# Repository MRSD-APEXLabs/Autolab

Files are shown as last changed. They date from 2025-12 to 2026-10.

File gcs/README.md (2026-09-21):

# GCS (Ground Control Station)

Operator-side stack: React UI, ROS2 GCS node bringup (rviz/rqt), MQTT bridges connecting the UI to ROS2, and an ELK monitoring stack.

## Layout

```
gcs/
├── docker/                          # docker-compose services for the GCS
│   ├── docker-compose.yaml          # gcs, gcs-real, ui, ui-dev, elasticsearch, kibana, filebeat
│   ├── gcs-base-docker-compose.yaml # shared ROS2 container definition (gcs-base)
│   ├── Dockerfile.gcs
│   └── monitoring/
│       ├── mosquitto/mosquitto.conf # MQTT broker config (ports 1883 + 9001 websocket)
│       └── filebeat/filebeat.yml
├── ui/                               # React web UI (Create React App)
└── ros_ws/src/
    ├── gcs_bringup/                  # top-level launch (rviz, rqt, domain_bridge, monitoring bridges, routine_executor)
    ├── gcs_monitoring/                # ROS2 <-> MQTT bridge nodes
    ├── routine_executor/              # runs operator-triggered routines (state machine)
    ├── rqt_gcs/                       # main rqt panel plugin (trajectory UI)
    └── rqt_autolab_control_panel/     # rqt operator control panel plugin
```

## UI

`gcs/ui` is a Create React App (React 19) that connects directly to the MQTT broker over WebSockets — it does not talk to ROS2 directly.

- Broker URL: `ws://<gcs-host>:9001` (`ui/src/App.js`), no ROS2 client involved.
- `mqtt` npm package used for pub/sub in the browser.

**Where it runs:**
- `ui` service (docker/docker-compose.yaml) — production build served by nginx on port `80` (override with `UI_PORT`). Built via `ui/Dockerfile.ui` (`prod` target: CRA build → nginx).
- `ui-dev` service — CRA dev server with hot reload on port `3000` (override with `UI_DEV_PORT`), profile `ui-dev`. Mounts `ui/src` and `ui/public` for live editing.
- Both build from `ui/Dockerfile.ui`; `dev` stage runs `npm start`, `prod` stage runs `npm run build` then serves via nginx.

Local (no Docker): `cd gcs/ui && npm install && npm start` (needs a broker reachable at `ws://localhost:9001`, e.g. from the `gcs` container's exposed `9001:9001` port).

Test/debug the UI's MQTT wiring without ROS2 using `ui/test_mqtt_status.py` (publishes/subscribes on `ros2/routine_executor/status` via the websocket port — see its docstring for usage).

## Bridges

MQTT is the transport between the browser UI and ROS2. Mosquitto runs inside the `gcs`/`gcs-real` container (`docker/monitoring/mosquitto/mosquitto.conf`): port `1883` for native MQTT, `9001` for MQTT-over-websockets (what the UI uses). Two ROS2 nodes in `gcs_monitoring` bridge the two worlds, both launched by `gcs_bringup/launch/gcs.launch.xml`:

- **`ros2_mqtt_bridge`** (`gcs_monitoring/ros2_mqtt_bridge.py`) — ROS2 → MQTT. Auto-discovers ROS2 topics every `ROS2MQTT_DISCOVERY_INTERVAL` seconds (default 10s), subscribes, and republishes each message as JSON to `ros2/<topic>` (e.g. `/odom` → `ros2/odom`). Skips `/tf`, `/tf_static`, `stereo` topics, and a hardcoded list of high-frequency/binary types (images, point clouds, IMU, joint states, TF, trajectories) to avoid flooding MQTT.
- **`mqtt_ros2_bridge`** (`gcs_monitoring/mqtt_ros2_bridge.py`) — MQTT → ROS2. Subscribes to a fixed set of UI command topics and republishes them as `std_msgs/String` on ROS2:
  - `cmd/routine_executor/start_routine_cmd` → `/routine_executor/start_routine_cmd`
  - `cmd/routine_executor/cancel` → `/routine_executor/cancel`

Both bridges connect to the broker at `MQTT_HOST`:`MQTT_PORT` (default `localhost:1883`, i.e. native MQTT — not the websocket port used by the browser), retrying until Mosquitto is up.

There's also a **`domain_bridge`** node (not MQTT — a ROS2 `domain_bridge` instance) configured by `gcs_bringup/config/domain_bridge.yaml`, which relays specific topics between ROS domain 0 (robot) and domain 1 (GCS) — behavior tree commands, joint states, fixed-trajectory commands, and bag-recording status/control.

## GCS ROS2 bringup

`ros2 launch gcs_bringup gcs.launch.xml` starts, in one process group:

1. `rviz2` with `rviz/gcs.rviz`
2. `rqt_gui` with the `config/gcs.perspective` layout (hosts the `rqt_gcs` and `rqt_autolab_control_panel` plugins)
3. `domain_bridge` (domain 0 ↔ 1 relay, see above)
4. `ros2_mqtt_bridge` and `mqtt_ros2_bridge` (monitoring bridges, see above)
5. `routine_executor_node` (executes operator-triggered routines; commanded via the MQTT bridges above)

All nodes `respawn` on crash. This launch runs automatically inside the `gcs`/`gcs-real` container when `AUTOLAUNCH=true` (see root `.env`), or manually via `autolab connect gcs` then `bws && sws && ros2 launch gcs_bringup gcs.launch.xml`.

## Monitoring stack (ELK)

`elasticsearch`, `kibana`, and `filebeat` services (docker/docker-compose.yaml) ship container logs for the `sitl`/default/`simple` profiles only — `gcs-real` uses `network_mode: host` and isn't covered by this stack. Kibana UI on `5601`, Elasticsearch API on `9200`. Config: `docker/monitoring/filebeat/filebeat.yml`.

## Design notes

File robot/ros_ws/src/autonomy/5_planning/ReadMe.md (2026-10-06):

# Planning: how to run it

The arm moves from step 4. Keep the E-stop in reach and the workspace clear. Nothing else may command the arm (no
joystick script, no UFactory Studio).

The point cloud, AprilTags and well plate detections come from the perception stack (`3_perception`). The planner
reads the topics it publishes: `/zed_pointcloud`, `/inspect/apriltags` and `/inspect/wellplates`.

## 1. Network (Thor)

```bash
ip -4 -br addr | grep enP2p1s0            # must be UP, 192.168.1.100
ping -c1 192.168.1.236 && echo ARM OK
ping -c1 192.168.1.101 && echo XAVIER OK
```

## 2. Camera hub (Xavier)

The hub runs at boot (`camera-hub.service`). Check that it answers:

```bash
curl -s http://192.168.1.101:8090/status   # "server": "camera_hub", "state": "streaming"
```

If it doesn't answer, restart it on the Xavier:

```bash
ssh autolab@192.168.1.101 'sudo systemctl restart camera-hub.service'
```

## 3. Perception (Thor host, not the container)

Use a new terminal. `~/.bashrc` already sets up ROS Jazzy, `ROS_DOMAIN_ID=1` and the loopback FastDDS profile.
The packages are built in `~/ros2_ws` from `~/apple_server_manip/2_manipulation`.

```bash
source ~/ros2_ws/install/setup.bash
source /home/labx/apple_server_manip/.venv/bin/activate        # torch for the depth nodes
ros2 launch camera_perception perception.launch.xml with_cameras:=true \
  depth_models_dir:=/home/labx/apple_server_manip/data/models
```

The hub streams one camera at a time, and the point cloud only comes from the ZED X. Select it (takes ~6 s):

```bash
ros2 service call /camera_hub/select_zedx std_srvs/srv/Trigger
```

Check:

```bash
ros2 topic hz /zed_pointcloud                  # up to 5 Hz
ros2 topic echo --once /inspect/wellplates     # a "wellplates" marker when a plate is in view
```

## 4. Planning stack (Thor → container): the arm enables here

After a `git pull`, rebuild in the container first: `autolab connect robot`, then `bws`.

```bash
xhost +local:
docker start autolab-robot-l4t-1                                          # skip if already running
docker exec autolab-robot-l4t-1 tmux kill-session -t robot_bringup        # stop the auto full-stack launch ("no server running" is fine)
docker exec -it autolab-robot-l4t-1 bash -lc 'export DISPLAY=:1 ROS_LOCALHOST_ONLY=1 FASTRTPS_DEFAULT_PROFILES_FILE=/home/robot/AutoLab/common/ros_packages/fastdds_loopback.xml; ros2 launch planning_bringup planning.launch.xml robot_ip:=192.168.1.236 show_rviz:=true'
# ready when "Received command: idle" repeats (~30 s); RViz opens with the planner path display
```

Always use `bash -lc`. Without it, the stack comes up on the wrong ROS domain and ignores every command.

## 5. Plan (Thor)

```bash
# terminal A
ros2 topic echo /planning_state
```

```bash
# terminal B: one at a time, wait for PLANNING → EXECUTING → SUCCESS
ros2 topic pub --once /planning_command std_msgs/String "{data: 'plan_home_offset'}"   # fixed safe pose, no camera needed. Do this first
ros2 topic pub --once /planning_command std_msgs/String "{data: 'plan_home'}"          # home point (via top_camera TF)
ros2 topic pub --once /planning_command std_msgs/String "{data: 'plan_april_1'}"       # 25 cm above AprilTag 1 (OT-2)
ros2 topic pub --once /planning_command std_msgs/String "{data: 'plan_april_2'}"       # 25 cm above AprilTag 2 (shaker)
ros2 topic pub --once /planning_command std_msgs/String "{data: 'plan_wellplate'}"     # 25 cm above the detected well plate
ros2 topic pub --once /planning_command std_msgs/String "{data: 'idle'}"
```

- **The obstacle cloud is frozen at the first `plan_*` command.** The planner forwards the latest `/zed_pointcloud`
  once to `/zed_pointcloud_frozen`, which is the only cloud MoveIt reads. Every later plan uses that cloud. To take a
  new one, restart the planning launch (step 4).
- `plan_april_<id>` and `plan_wellplate` wait up to 10 s for a detection less than 1 s old, or end in `ERROR`.
- The wrist must be within ~11° of straight down before the first plan, or you get
  `Waypoint 0 FAILED ee_down constraint`.
- RViz shows two lines per plan: orange is the raw planner path, cyan is the path after shortcutting.
- The planner is chosen by `PLANNER` in `global_planner/src/move_to_pose_node.cpp` (`RRT_CONNECT` |
  `INFORMED_RRTSTAR` | `PRM`). After changing it, rebuild and relaunch step 4:

```bash
docker exec autolab-robot-l4t-1 bash -lc 'cd ~/AutoLab/robot/ros_ws && colcon build --symlink-install --packages-select global_planner'
```

## 6. Stop

Ctrl-C the planning launch (step 4), then Ctrl-C the perception launch (step 3).

## Code

The main logic is in `global_planner/src/move_to_pose_node.cpp`. The commands on `/planning_command`
(`std_msgs/String`) are `plan_april_<id>`, `plan_wellplate`, `plan_home`, `plan_home_offset` and `idle`.

Future improvements:
- [Design] Put all config params in one file.
- [Design] `move_to_pose_node.cpp` is ~1000 lines; split it into smaller pieces.

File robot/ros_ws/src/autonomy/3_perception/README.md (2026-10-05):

# 3_perception: ZED X / ZED X Nano cameras, stereo depth, camera UI, perception and live ACT inference

This folder is self-contained. It holds the camera stack and the inference half of the teleop/ACT pipeline, ready
to move into a larger codebase:

| folder | what | depends on |
|---|---|---|
| `zedx_nano_camera/` | ROS 2 package (ament_python). Publishes a camera feed from the Xavier: JPEG, raw BGR and `CameraInfo` for each eye. Serves either camera of the camera hub (`camera` parameter). Also holds `camera_hub_node`, the ROS bridge to the hub (status topic, select services) | `rclpy`, `sensor_msgs`, `std_srvs`, `cv_bridge`, numpy, OpenCV. No ZED SDK |
| `zedx_nano_depth/` | ROS 2 package. Subscribes to the stereo pair, rectifies it, computes depth with RAFT-Stereo (GPU) or SGBM (CPU) and publishes depth plus the rectified left image | `zedx_nano_camera`; torch for the neural backend |
| `camera_ui/` | ROS 2 package. Web page on port 8001 that switches the hub between the two cameras and shows the active camera's RGB and depth. Its launch file starts the whole camera stack | `zedx_nano_camera`, `sensor_msgs`, `std_srvs`, `cv_bridge`, numpy, OpenCV |
| `camera_perception/` | ROS 2 package. AprilTags, YOLO detections and (ZED X only) a point cloud from the depth node's outputs, published under the topic names of the old Autolab `pc3.py` bridge (`/inspect/*`, `/servo/*`, `/zed_pointcloud`) | `zedx_nano_depth`, `camera_ui` (launch only), `cv_bridge`; pip: `pupil-apriltags`, `ultralytics` (torch) |
| `xavier_camera_hub/` | Not a ROS package (`COLCON_IGNORE`). HTTP server that runs **on the Xavier** (`/home/autolab/camera_hub/`) and streams one camera at a time. See [its README](xavier_camera_hub/README.md) | Python 3.8, numpy, OpenCV, pyzed (ZED X), `v4l2-ctl` (Nano) |
| `act_inference/` | Plain Python, not a ROS package (`COLCON_IGNORE`). Live ACT rollout on the xArm6. Contains a trimmed copy of the ACT/DETR model code | the ROS packages above as libraries; torch, xArm SDK |

The package names still say "nano", but `zedx_nano_camera` and `zedx_nano_depth` serve both cameras.

Relationship:

```
Xavier: xavier_camera_hub (port 8090), streams ONE camera at a time
   │  ZED X (SN 42757821, base) via pyzed   or   ZED X Nano (SN 99292912, wrist) via raw V4L2
   │  /select, /status, /cameras/<cam>/{video_feed/stereo,calibration.conf,info}, /time
   │
   ├──► camera_hub_node ──► /camera_hub/status, /camera_hub/select_{zedx,zedx_nano}, /camera_hub/release
   ├──► zedx_nano_camera (camera:=zedx)      ──► /zedx/{left,right}/…      ──► zedx_nano_depth ──► /zedx/depth/…
   ├──► zedx_nano_camera (camera:=zedx_nano) ──► /zedx_nano/{left,right}/… ──► zedx_nano_depth ──► /zedx_nano/depth/…
   │                                                                             │
   │                               camera_ui (http://<thor>:8001/) ◄─────────────┤ both namespaces + /camera_hub
   │                               camera_perception ◄───────────────────────────┤ /inspect/*, /zed_pointcloud, /servo/*
   │                               act_inference --camera-source ros ◄───────────┘
   └──► legacy root routes (Nano only): act_inference --camera-source nano-stream, teleop/nano_stream.py
```

The nodes of the camera that is not selected stay connected to the hub and wait; they start publishing within
about a second of a switch. Both camera sources of `act_inference` feed the policy identical frames. The
rectification maps, depth pipeline and ACT preprocessing are copies of `teleop/` and `act/` (see
[Verification](#verification)). The old Nano-only server (`scripts/zedx_nano_v4l2_stream.py`,
`zedx-nano-stream.service`) stays in the repo root; the hub replaces it on port 8090 and keeps its routes.

## Camera UI (ZED X and ZED X Nano)

Build the packages (see [Build](#build)), then on the Thor:

```bash
source /opt/ros/humble/setup.bash && source ~/ros2_ws/install/setup.bash
source /home/labx/apple_server_manip/.venv/bin/activate          # torch for the RAFT depth nodes
ros2 launch camera_ui camera_ui.launch.xml models_dir:=/home/labx/apple_server_manip/data/models
```

Open `http://<thor>:8001/`. The two buttons at the top right select the ZED X (base) or the ZED X Nano (wrist);
**Release** stops both. The left panel shows the rectified left image and the right panel shows depth (TURBO:
red near, blue far, black invalid) with its colorbar, auto range or a fixed near/far range in mm. Hovering over
either image shows the depth and the optical-frame XYZ at that pixel. **PNG** saves the RGB image, **PNG 16-bit**
saves the depth in mm. The rates, frame age, valid-pixel ratio and median depth appear under each panel.

A switch takes about 6 s to the ZED X (the ZED SDK opens the camera) and about 2 s to the Nano. The same switch
from a terminal or another node:

```bash
ros2 service call /camera_hub/select_zedx std_srvs/srv/Trigger
ros2 service call /camera_hub/select_zedx_nano std_srvs/srv/Trigger
ros2 service call /camera_hub/release std_srvs/srv/Trigger
ros2 topic echo --once /camera_hub/status                        # JSON: active camera, state, rates
curl -X POST -H 'Content-Type: application/json' -d '{"camera": "zedx"}' http://<thor>:8001/api/select
```

`/api/select` accepts only `Content-Type: application/json` and refuses cross-origin requests, so another web
page cannot switch the camera. The hub's own page, `http://192.168.1.101:8090/`, also switches cameras and shows
the raw left/right preview.

`camera_ui.launch.xml` arguments:
- `with_cameras` (true): also start `cameras.launch.xml`, i.e. the hub bridge plus a camera node and a depth node
  per camera. Use `with_cameras:=false` when the camera stack already runs.
- `ui_host` (0.0.0.0) and `ui_port` (8001): where the page is served. The page can switch cameras, so use
  `ui_host:=127.0.0.1` to keep it off the network.
- `host` and `port`: the Xavier hub (192.168.1.101, 8090).
- `backend`, `models_dir` and `repo`: passed to both depth nodes.
- `zedx_depth_model` (fast-foundation) and `zedx_nano_depth_model` (`model`, i.e. raft-realtime): the depth
  model per camera. The base camera takes accuracy over rate, the wrist camera the rate
  (see [Depth models](#depth-models)). `model` sets the default for any camera without its own argument.
- `zedx_temporal_frames` (5) and `zedx_nano_temporal_frames` (1): the temporal median per camera.
- `ui_params_file`: the UI parameters, `config/camera_ui.yaml` by default.

`ros2 launch camera_ui cameras.launch.xml` starts the camera stack without the page.

UI HTTP API, for scripts:

| request | answer |
|---|---|
| `GET /api/status` | hub status, per-camera stream rates, depth statistics, intrinsics |
| `POST /api/select` `{"camera": "zedx" \| "zedx_nano" \| null}` | switch (null releases); waits up to 45 s for the first frame |
| `GET /api/depth_at?camera=&u=&v=` | depth (mm) and optical-frame XYZ (mm) at normalized image coordinates |
| `GET /stream/<cam>/rgb.mjpg` | rectified left image; the raw JPEG while no depth node runs |
| `GET /stream/<cam>/depth.mjpg?near=&far=&auto=1` | colorized depth |
| `GET /snapshot/<cam>/rgb.png`, `/snapshot/<cam>/depth.png` | the latest frame; depth as 16-bit PNG in mm |

## Perception: AprilTags, YOLO and the ZED X point cloud

`camera_perception` replaces the Xavier's Autolab-Camera-Edge "inspect" (ZED X) and "servo" (Nano) workers and the
`~/coding/Autolab/pc3.py` bridge that republished them. It runs on the Thor, on the rectified image and depth of the
camera stack above, and publishes under the topic names `pc3.py` used, so the planner (`move_to_pose_node`) and
MoveIt read it unchanged. There is one node per camera: `/zedx/zedx_perception` and `/zedx_nano/zedx_nano_perception`.
Like the depth nodes, the node of the camera the hub is not streaming logs once that it is idle and waits.

One-time setup, in the venv that runs the nodes (it must see the system site packages). `--no-deps` keeps pip from
installing `opencv-python`, which would shadow the system cv2 that `cv_bridge` uses:

```bash
source /home/labx/apple_server_manip/.venv/bin/activate
pip install pupil-apriltags
pip install --no-deps ultralytics 'filelock>=3.16.1' cloudpickle ultralytics-thop nvidia-ml-py
```

The YOLO weights are in `data/models/yolo/`:
- `best_wrist.pt`: oriented boxes, class `wellplate`, from Camera-Edge servo. The default for both cameras.
- `best_top.pt`: the same kind of model, from Camera-Edge inspect. It did not find the clear plate on the ZED X
  deck (below).
- `best_seg.pt`: segmentation, from `~/coding/Autolab`.

Run it next to the camera stack (the camera UI launch), or start the stack with it:

```bash
source /opt/ros/humble/setup.bash && source ~/ros2_ws/install/setup.bash
source /home/labx/apple_server_manip/.venv/bin/activate
ros2 launch camera_perception perception.launch.xml                          # camera stack already running
ros2 launch camera_perception perception.launch.xml with_cameras:=true \
  depth_models_dir:=/home/labx/apple_server_manip/data/models                  # also start hub bridge, camera, depth
ros2 launch camera_perception perception.launch.xml zedx_nano:=false cloud_mode:=snapshot fresh:=true
```

Use the same `ROS_DOMAIN_ID` as the camera stack and the planner.

### Topics

| `pc3.py` | camera_perception | type | contents |
|---|---|---|---|
| `/inspect/apriltags` | same | `MarkerArray` | `DELETEALL`, then one red 2 cm `SPHERE` per tag with a pose: `id` = tag id, ns `apriltags`, orientation = tag frame. Nothing else, because the planner stores every ADD marker's position under its id |
| `/inspect/wellplates` | same | `MarkerArray` | `DELETEALL`, then per detection with a pose a green `CUBE` (ns `wellplates`, id i, metric size) and a label (ns `wellplates_text`, id 1000+i). Detections are sorted by ascending confidence, so the most confident one is the last `wellplates` marker, the one the planner takes |
| `/zed_pointcloud` | same | `PointCloud2` | x, y, z float32 (+ packed `rgb`), frame `top_camera`, for MoveIt's octomap |
| `/inspect/image`, `/inspect/annotated_image` | same | `Image` bgr8 | the input image, and the image with tags, boxes and axes drawn. Published only while subscribed |
| – | `/inspect/json` | `String` | the frame's tags and detections: pixel geometry, poses, pose source, tag size measured by depth, reprojection error |
| – | `/inspect/capture_snapshot` | `std_srvs/Trigger` | snapshot mode: capture a new cloud |
| `/servo/image`, `/servo/annotated_image`, `/servo/detections` | same | as above | Nano. Detections: the best one only, ns `servo_detections` |
| – | `/servo/apriltags`, `/servo/json` | as above | Nano tags and JSON |
| `/servo/target` | **not published** | | it needs a Nano hand-eye calibration, which doesn't exist yet |

All outputs carry the image stamp. The ZED X outputs are labelled `top_camera`, the frame that the robot's TF tree
(`Chassis_1 → top_camera`) and the planner use for this camera. The launch file also publishes an identity
`top_camera → zedx_left_camera_optical_frame` (`top_camera_tf:=false` turns it off), so the `/zedx` camera
topics fit into that tree too. The Nano outputs keep `zedx_nano_left_camera_optical_frame`.

### What is computed

- **AprilTags:** `pupil_apriltags`, tag36h11, ids 0, 1, 2, 21 and 22, 62.5 mm, at full resolution.
  - Pose from `solvePnPGeneric` (IPPE_SQUARE) on the corners and the tag size. The depth inside the tag gives a
    plane that picks between the two mirror-image PnP solutions and measures the tag's actual size. The node warns
    when that size is more than 15 % off; set `apriltags.sizes` (`'21=0.075'`) for tags printed at another size.
  - `apriltags.position: depth` takes the position from the depth plane instead of the size.
  - The orientation is the AprilTag library's tag frame (x right, y down, z into the tag, in the tag's own
    orientation). The Camera-Edge code built it from image-sorted corners, so its orientation differed.
    `calibrate_top_camera.py` fits position only by default.
  - A small tag seen face-on (~40 px) has a few degrees of tilt uncertainty. Its position and in-plane angle stay
    sharp.
- **YOLO:** ultralytics, on the GPU (falls back to CPU). Oriented-box, box and segmentation models are handled.
  The ZED X keeps only the class `wellplate` (`yolo.classes`), since the planner takes the last marker on
  `/inspect/wellplates` whatever its class.
  - On the ZED X the model input gets CLAHE first (`yolo.clahe_clip` 3, `yolo.clahe_tiles` 4; contrast
    equalization of the lightness in 4×4 tiles). The deck is dim, and a clear plate on it is invisible to the
    models without it. Outputs and the annotated image use the original image.
  - Each detection is placed with a RANSAC plane fit on the depth inside its box or mask. Position: the centre ray
    meets the plane. z: the plane normal toward the camera. x: along the box's width, which is the long side for
    oriented boxes. Size: in metres.
  - Detections without valid depth appear in the JSON and the annotated image but get no marker. `pc3.py` gave
    those a pixel-scaled placeholder.
  - If the model fails to load or run, the node logs the error and continues with tags and the cloud.
- **Point cloud (ZED X only):**
  - Every 4th pixel of the depth, cropped to x, y ∈ ±0.6 m and z ∈ 0.2–1.7 m (camera frame). Points on depth
    edges (a jump over 2 % of the depth per pixel) are dropped, then one point is kept per 1 cm voxel: about
    10k points per cloud.
  - `cloud_mode:=live` (default): a new cloud up to 5 times a second, so the octomap follows the scene.
  - `cloud_mode:=snapshot`: `pc3.py`'s behaviour. 10 frames are stacked once, saved to
    `~/.ros/camera_perception/zedx_snapshot.npy` and republished at 5 Hz stamped with the current time. A cached
    cloud is loaded at start-up, even without a camera. `pc3.py`'s N×3 `.npy` files load as well.
    `/inspect/capture_snapshot` or `fresh:=true` captures a new one.
  - With `fresh:=true` or after `capture_snapshot`, the old cloud stays published until the new one is complete.
    Then the node calls `/clear_octomap` and publishes the new cloud. So MoveIt is never left without obstacles,
    even if the hub is streaming the Nano. If move_group doesn't answer within 40 timer ticks (8 s at 5 Hz), the
    node publishes anyway. Live mode with `fresh:=true` clears the same way, before its first cloud.
    A failed cache write is logged, and the cloud is still published.

The ZED X node processes at most 10 frames/s (`max_rate`). At every frame (~16/s) it would take about 1.3 CPU
cores, mostly for the full-resolution tag detection. The Nano node processes every frame.

`perception.launch.xml` arguments:
- `zedx`, `zedx_nano` (true): which cameras get a node.
- `yolo_models_dir` (`data/models/yolo`), `zedx_model` (best_wrist.pt), `zedx_nano_model` (best_wrist.pt),
  `device` (cuda:0).
- `cloud_mode` (live | snapshot) and `fresh` (false).
- `top_camera_tf` (true).
- `zedx_params_file`, `zedx_nano_params_file`: `config/zedx.yaml` and `config/zedx_nano.yaml` hold every other
  parameter, with comments.
- `with_cameras` (false), `host`, `port`, `depth_backend`, `depth_models_dir`, `depth_repo`: for starting the
  camera stack too. The per-camera depth models are the camera stack's defaults; override them there.
  `perception_bringup` passes the same arguments through.

`camera_perception`, `camera_ui`, `zedx_nano_camera` and `zedx_nano_depth` are shared with
`apple_server_manip/2_manipulation`, where they are developed on Jazzy. The two copies are kept identical
except that this one ships the YOLO weights inside `camera_perception` (`models/yolo`, installed by
`setup.py`) and defaults `yolo_models_dir` to the package share. Port changes both ways.

## Live ACT inference

Prediction-only by default: robot state is read, the policy runs, the limited targets are
printed, and the arm is not enabled or commanded. Keep `policy_best.ckpt`, `config.pkl` and
`dataset_stats.pkl` together in the checkpoint folder. RGB versus RGB-D is detected from the checkpoint.

From the repo root, with the project venv:

```bash
OMP_NUM_THREADS=2 .venv/bin/python 2_manipulation/act_inference/run_act_inference.py \
  --ckpt-dir data/act_ckpts/xarm6_rgbd --duration-sec 30 --preview \
  --depth-models-dir data/models
```

`--depth-models-dir data/models` reuses the RAFT weights already in the repo. Without it the
weights go to `$ZEDX_NANO_DEPTH_MODELS` or `~/.cache/zedx_nano_depth` and are downloaded
(40 MB) on the first run.

For an operator-attended run, place the arm at the demonstrated start pose, stop any other
controller (teleop, AutoLab planning) and add `--execute`:

```bash
OMP_NUM_THREADS=2 .venv/bin/python 2_manipulation/act_inference/run_act_inference.py \
  --ckpt-dir data/act_ckpts/xarm6_rgbd --duration-sec 5 --translation-speed 0.01 \
  --depth-models-dir data/models --execute --preview
```

Ctrl-C, Enter, or `q`/Esc in the preview stops the run. Every target is speed-limited
(`--translation-speed` 0.025 m/s, `--rotation-speed` 0.1 rad/s) and must stay inside
`--workspace-radius` (0.1 m) of the start pose. The run stops if a prediction is older than
`--prediction-timeout` (0.75 s) or the camera frame is stale (`--max-frame-age` 0.25 s plus
two depth periods). Orientation is held unless `--enable-rotation` is given. There is no gripper output.

### Camera sources

- `--camera-source nano-stream` (default) reads stereo pairs from the Xavier (`--camera-host`
  192.168.1.101, `--camera-port` 8090) and computes depth in this process (`--depth-backend
  neural|sgbm`, `--depth-model`, `--depth-width`). It needs no ROS.
- `--camera-source ros --ros-namespace /zedx_nano` reads `left/image_rect_color`,
  `depth/image_rect` and `depth/camera_info` from a running `zedx_nano_depth` node, so one
  depth network serves both the robot stack and the policy. Source ROS first
  (`source /opt/ros/humble/setup.bash`) and use the same `ROS_DOMAIN_ID` as the nodes. The
  `--depth-*` options don't apply here; the depth node's parameters do. It runs a private
  rclpy context, so it can be embedded in a process that already uses rclpy.

`run_act_inference.py --help` lists all options. `act_inference/requirements.txt` lists the Python dependencies.

### Using it as a library

`act_inference/act_inference/__init__.py` adds `zedx_nano_camera/` and `zedx_nano_depth/` to
`sys.path` when they sit next to it. So once `2_manipulation/act_inference` is on the path, no
build step is needed:

```python
import sys; sys.path.insert(0, '2_manipulation/act_inference')
from pathlib import Path
from act_inference.config import InferenceConfig, RolloutConfig
from act_inference.rollout import run_act_rollout

run_act_rollout(InferenceConfig(camera_source='ros', ros_namespace='/zedx_nano'),
                RolloutConfig(ckpt_dir=Path('data/act_ckpts/xarm6_rgbd'), duration_sec=30))
```

Lower-level pieces:
- `rollout.load_policy` and `rollout.predict_chunk` for the model.
- `cameras.make_camera` for a `CameraFrame` source.
- `robot.XArm6Robot(read_only=True)` for the arm.

## ROS 2 packages

### Build

The packages were originally built and tested against ROS 2 Jazzy (Python 3.12); this repo runs Humble
(Python 3.10). Audited 2026-09-22: no Jazzy-only rclpy/launch API or Python 3.11+/3.12-only syntax found in
`zedx_nano_camera`, `zedx_nano_depth`, `camera_ui` or `camera_perception` — none was ever run on Humble though,
so treat a first build as unverified. Link or copy them into a workspace:

```bash
mkdir -p ~/ros2_ws/src && ln -s /home/labx/apple_server_manip/2_manipulation ~/ros2_ws/src/2_manipulation
cd ~/ros2_ws && source /opt/ros/humble/setup.bash
colcon build --packages-select zedx_nano_camera zedx_nano_depth camera_ui camera_perception
source install/setup.bash
```

colcon skips `act_inference` and `xavier_camera_hub` because of their `COLCON_IGNORE`. Build **without**
`--symlink-install`. The node scripts then use `#!/usr/bin/env python3`, so they run in whichever Python is first
on `PATH`. With `--symlink-install`, colcon writes `#!/usr/bin/python3` into them instead, and the depth nodes
fail because the system Python has no CUDA torch. The neural depth
backend needs torch, so activate a venv that has torch and the system site packages before
`ros2 launch`, e.g. `source /home/labx/apple_server_manip/.venv/bin/activate`. The camera node
and the `sgbm` backend need only the system Python. torch isn't a rosdep key, so `package.xml` doesn't declare it.

### Launch

The camera UI's launch file starts the full two-camera stack (see [Camera UI](#camera-ui-zed-x-and-zed-x-nano)):

```bash
ros2 launch camera_ui camera_ui.launch.xml models_dir:=/home/labx/apple_server_manip/data/models   # stack + page
ros2 launch camera_ui cameras.launch.xml models_dir:=/home/labx/apple_server_manip/data/models      # stack only
ros2 launch zedx_nano_camera camera_hub.launch.xml                                                 # hub bridge only
```

Single cameras:

```bash
# ZED X depth (also starts its camera node) in /zedx
ros2 launch zedx_nano_depth zedx_nano_depth.launch.xml camera:=zedx namespace:=zedx \
  models_dir:=/home/labx/apple_server_manip/data/models

# Nano camera only
ros2 launch zedx_nano_camera zedx_nano_camera.launch.xml host:=192.168.1.101

# depth, also starts the camera (with_camera:=true is the default)
ros2 launch zedx_nano_depth zedx_nano_depth.launch.xml models_dir:=/home/labx/apple_server_manip/data/models

# depth only, camera already running in the same namespace
ros2 launch zedx_nano_depth zedx_nano_depth.launch.xml with_camera:=false

# CPU depth, no torch needed
ros2 launch zedx_nano_depth zedx_nano_depth.launch.xml backend:=sgbm
```

Launch arguments:
- Camera: `namespace` (zedx_nano), `camera`, `name` (node name), `host`, `port`, `sensor`, `params_file`.
- Depth: `namespace`, `with_camera`, `camera`, `host`, `port`, `backend`, `model`, `models_dir`, `params_file`.
- Hub bridge: `host`, `port`, `params_file`.

`camera` selects a hub camera: `zedx` or `zedx_nano`. It also names the frames. Use a matching `namespace`.
The default, `''`, reads the hub's legacy root routes, which serve the Nano, and the old Nano-only server.
A single-camera launch does not switch the hub; select its camera in the UI or with the
`/camera_hub/select_*` services (with the hub bridge running) or `POST /select` on the Xavier.

The remaining parameters are read from `config/*.yaml`. Each file's header says which values the launch file overrides.

### Topics (namespaces `/zedx` and `/zedx_nano`)

Each camera has its own namespace with the same topics. The camera UI launch uses `/zedx` for the ZED X and
`/zedx_nano` for the Nano.

| topic | type | from | notes |
|---|---|---|---|
| `{left,right}/image_raw/compressed` | `CompressedImage` | camera | the Xavier's JPEG, forwarded without re-encoding |
| `{left,right}/image_raw` | `Image` bgr8 | camera | unrectified; decoded only while something subscribes |
| `{left,right}/camera_info` | `CameraInfo` | camera | factory K, D and stereo rectification R, P. Right `P[0,3] = -fx·B` in meters |
| `depth/image_rect` | `Image` 16UC1 | depth | depth in mm, 0 = invalid, aligned to `left/image_rect_color` |
| `depth/camera_info` | `CameraInfo` | depth | rectified pinhole model (D = 0) for `depth/image_rect` and `left/image_rect_color` |
| `left/image_rect_color` | `Image` bgr8 | depth | the rectified left image that the depth belongs to |
| `depth/colorized` | `Image` bgr8 | depth | preview: red near, blue far, black invalid. Computed only while subscribed |

With `sensor:=left` or `right`, the camera publishes only that eye; the depth node needs `stereo`.

The hub bridge, `camera_hub_node`, is not namespaced:

| name | type | notes |
|---|---|---|
| `/camera_hub/status` | `std_msgs/String` (JSON), transient local | the hub's `/status` (`active`, `state`, `error`, per-camera `fps`) plus `reachable`, `poll_error`, `hub_url`; published after every poll |
| `/camera_hub/select_zedx`, `/camera_hub/select_zedx_nano` | `std_srvs/Trigger` | switch the hub; returns when the camera streams (`success`, `message` e.g. `zedx streaming`) or fails |
| `/camera_hub/release` | `std_srvs/Trigger` | stop both cameras |

### Parameters

| node | parameter | default | |
|---|---|---|---|
| camera | `host`, `port` | 192.168.1.101, 8090 | Xavier camera hub |
| camera | `camera` | '' | zedx or zedx_nano; '' = the hub's legacy root routes (the Nano) |
| camera | `sensor` | stereo | stereo, left or right |
| camera | `timeout` | 3.0 s | HTTP timeout; longest stall before reconnecting |
| camera | `left_frame_id`, `right_frame_id` | '' | '' = `<camera>_{left,right}_camera_optical_frame` (`zedx_nano_…` for camera '') |
| camera | `clock_sync_period` | 10 s | Xavier clock re-synchronization |
| camera | `max_sync_uncertainty` | 0.05 s | reject a clock sync that is less precise than this |
| camera | `reconnect_delay` | 1.0 s | |
| camera | `inactive_poll_period` | 1.0 s | how often to retry while the hub streams the other camera |
| depth | `backend` | neural | neural (RAFT-Stereo, GPU) or sgbm (OpenCV, CPU) |
| depth | `model` | raft-realtime | raft-realtime, raft-middlebury, fast-foundation or a `.pth` path |
| depth | `models_dir` | '' | '' = `$ZEDX_NANO_DEPTH_MODELS` or `~/.cache/zedx_nano_depth`. Missing RAFT weights are downloaded |
| depth | `repo` | '' | fast-foundation only: checkout path ('' = `<models_dir>/Fast-FoundationStereo`). The repo's copy is `third_party/Fast-FoundationStereo` |
| depth | `match_width` | 640 | px; the width at which disparity is computed |
| depth | `temporal_frames` | 1 | >1 publishes the per-pixel median of that many frames (the camera stack gives the ZED X 5). For a camera that does not move; the window is dropped after a 1 s gap or a new calibration |
| depth | `max_depth_mm` | 4000 | farther depth is published as 0 |
| depth | `input_transport` | compressed | compressed (JPEG) or raw (`image_raw`) |
| depth | `colorize_near_mm`, `colorize_far_mm` | 100, 1000 | `depth/colorized` range |
| camera_hub | `host`, `port` | 192.168.1.101, 8090 | Xavier camera hub |
| camera_hub | `cameras` | [zedx, zedx_nano] | one `select_<camera>` service each |
| camera_hub | `poll_period`, `timeout` | 1.0 s, 3.0 s | `/status` polling |
| camera_hub | `select_timeout` | 30 s | how long a select waits for the camera's first frame |
| camera_ui | `host`, `port` | 0.0.0.0, 8001 | where the page is served (launch: `ui_host`, `ui_port`) |
| camera_ui | `cameras`, `labels` | [zedx, zedx_nano], [ZED X (base), ZED X Nano (wrist)] | topics are read from `/<camera>/…` |
| camera_ui | `max_fps`, `jpeg_quality` | 15, 80 | per browser stream |
| camera_ui | `stale_after` | 1.0 s | older frames are marked stale on the page |
| camera_ui | `hub_node` | /camera_hub | the hub bridge's status topic and services |

### Depth models

Measured on the Jazzy machine (Thor, CUDA) against the ZED X: 10 stereo pairs of the room and floor at 1.2-3.7 m,
and 10 of the Opentrons deck at 0.86 m. *Flicker* is the median standard deviation of one pixel's depth over the
pairs of a still scene; *plane residual* is what a plane fitted in 15x15 windows leaves, i.e. how rough a locally
flat surface looks.

| ZED X, `match_width` 640 | flicker (room) | flicker (deck) | plane residual | per pair |
|---|---|---|---|---|
| sgbm | 33.7 mm | | 31.9 mm | 29 ms |
| raft-realtime | 34.7 mm | 35.7 mm | 2.1 mm | 51 ms |
| raft-realtime + median of 5 | | 10.5 mm | 2.6 mm | 51 ms |
| raft-middlebury | 17.6 mm | | 8.9 mm | 481 ms |
| fast-foundation | 6.1 mm | 11.4 mm | 1.1 mm | 171 ms |
| **fast-foundation + median of 5** | | **3.2 mm** | 1.1 mm | 171 ms |

So the camera stack runs the ZED X on fast-foundation with `temporal_frames: 5` (~6-9 fps, which the base camera
can afford: perception caps at 10 Hz and the point cloud at 5 Hz) and leaves the Nano on raft-realtime with no
median, because the visual servo needs the rate and the low lag, not the millimetres. The median is per pixel over
the last N frames (`np.partition`, 9 ms); its window is dropped when the input stops for a second or the
calibration changes, so a camera switch never mixes two scenes.

fast-foundation is Fast-FoundationStereo. **Its checkout is not in this repo**: point `repo` at one (or put it in
`<models_dir>/Fast-FoundationStereo`, or set `FAST_FOUNDATION_STEREO_DIR`), with its
`pretrained_models/model_best_bp2_serialize.pth`. Without it the node logs the error and falls back to
raft-realtime, so the stack keeps publishing depth — noisier, and the log says why.

Matching at 960 instead of 640 does not help (18.4 mm on the deck, twice the time), and neither does raising the
hub's JPEG quality: compressing the pairs again at quality 60 wrecks RAFT (plane residual 5.6 -> 42.3 mm) but
barely touches fast-foundation (2.4 -> 5.1 mm). What remains is the stereo geometry: with fx 365 px at 960 and a
120.02 mm baseline, one pixel of disparity error is 11 mm at 0.7 m and grows with the square of the range.

### Stamps, frames and clocks

- Header stamps are the capture time. The camera node maps the Xavier's clock to its own ROS clock and re-synchronizes every 10 s.
- Both eyes of a stereo pair carry the left capture stamp. The depth node pairs left and right by that exact stamp.
- The depth outputs keep the stamp and `frame_id` of the left image. As with `image_proc`, the rectified images keep the camera's frame id.
- No TF is published. The integrating stack provides the transforms to `zedx_nano_left_camera_optical_frame` (wrist) and `zedx_left_camera_optical_frame` (base).
- The ZED X images come from the ZED SDK unrectified, like the Nano's, so both go through the same rectification from the factory calibration. The ZED X baseline is 120 mm and the Nano's is 18 mm, so the ZED X is less precise up close and reaches farther.
- The depth node always works on the newest pair and drops pairs that arrive while it is busy, so latency stays at one compute period.
- The camera node reconnects on its own. While the hub streams the other camera it logs one line and waits; the depth node logs once that it is idle. The depth node exits if its backend fails, e.g. when the GPU worker process dies.
- `act_inference --camera-source ros` compares these stamps with its local clock. Run it on the same machine as the camera node, or keep both clocks synchronized (chrony/PTP).

## Tests

```bash
cd 2_manipulation
source /opt/ros/humble/setup.bash
export ROS_DOMAIN_ID=73 ROS_AUTOMATIC_DISCOVERY_RANGE=LOCALHOST   # keep test traffic off the robot network
ZEDX_NANO_DEPTH_TEST_MODELS=/home/labx/apple_server_manip/data/models \
  ../.venv/bin/python -m pytest -q -p no:cacheprovider zedx_nano_camera/test zedx_nano_depth/test act_inference/tests camera_ui/test
YOLO_OFFLINE=1 ../.venv/bin/python -m pytest -q -p no:cacheprovider camera_perception/test
../.venv/bin/python -m pytest -q -p no:cacheprovider xavier_camera_hub/tests    # the hub, with fake cameras
```

The tests use a synthetic Xavier server, a stub robot and a tiny random checkpoint. They need
no hardware and never connect to the arm. The camera UI page test drives headless Chrome and is skipped without
`google-chrome` (or chromium) and the `websocket-client` package. The RAFT test runs only with a CUDA GPU and
`ZEDX_NANO_DEPTH_TEST_MODELS`; the ROS tests are skipped when rclpy isn't importable. The perception tests render
tags and planes with exact depth; they load the real YOLO models from `data/models/yolo` (or
`CAMERA_PERCEPTION_TEST_MODELS`) when present and use a fake detector for the node. In a workspace,
`colcon test --packages-select zedx_nano_camera zedx_nano_depth camera_ui camera_perception && colcon test-result --verbose`
runs the ROS packages' tests.

## Verification

Checked on this machine (Jetson, Jazzy, torch 2.14 + CUDA) against the original `teleop/` and `act/` code:

- **Rectification maps:** bit-identical to `teleop` `StereoCalibration`, with 5-coefficient and rational distortion. This holds both from the `.conf` directly and through `CameraInfo`.
- **ACT actions:** bit-identical to the original for an RGB checkpoint and an RGB-D checkpoint.
- **Camera frames:** image, depth, headers, capture time and calibration are identical to the original `NanoStreamCamera` with SGBM and with RAFT.
- **ROS against a fake Xavier at 15 fps:** about 14 Hz on every topic, for SGBM and for RAFT.
- **Rollout, both camera sources:** with a stub robot, prediction-only rollouts run the 50 Hz loop.
- **Live cameras (2026-09-22), full camera UI stack on the Thor against the hub on the Xavier:**
  - Nano: 30 Hz raw, depth at 16-17 fps (RAFT realtime, ~42 ms per pair), 100 % valid pixels.
  - ZED X: depth at ~16 fps, 100 % valid pixels.
  - Switches both ways from the page and from the `/camera_hub/select_*` services: ~6.2 s to the ZED X,
    ~1.9 s to the Nano.
  - `teleop/nano_stream.py` still reads the Nano at 30 fps through the hub's legacy routes.
- **Perception (2026-09-22), on the running camera stack.** Outputs were kept on test topics, not the `pc3.py` names:
  - ZED X, every frame: 15 frames/s of the 16-17 Hz depth. Per frame: tags 38 ms (CPU), YOLO 22 ms (GPU).
    Clouds: 8-9 ms, ~4.3/s, 9.5-12k points in `top_camera`. About 1.3 CPU cores.
  - The 10 Hz `max_rate` cap, checked on the Nano's 14 Hz depth: 10.0 frames/s.
  - ZED X tags 1 and 21 at 0.7-0.8 m: position jitter under 1 mm. The depth measured them at 64.0 and 60.9 mm,
    so 62.5 mm fits both.
  - Nano: 13.8 frames/s, tags 26 ms, YOLO 33 ms.
  - Nodes idle while the hub streams the other camera, and exit cleanly on Ctrl-C.
  - Snapshot mode and `/clear_octomap` were tested only against fakes (unit tests).
- **Wellplate detection (2026-09-22), 8 saved ZED X frames** of a clear 96-well plate on the Opentrons deck:
  - Tried `best_top.pt` (current and two older versions from the Xavier), `best_wrist.pt` (two versions) and
    `best_seg.pt`. For each: 26 preprocessings (brightness/contrast, gamma, CLAHE, auto levels, gray world,
    sharpening) × full frame at 640 and 960, 2×2 tiles, or a deck crop.
  - `best_top.pt` scored at most 0.003 on the plate in every setting. Its only hit (0.40) was an empty deck slot.
  - `best_wrist.pt` + CLAHE: 0.90–0.92 on every frame, with no other detection above 0.01. Clip limits of 1.5–4
    all score 0.85 or more. The same model without CLAHE: nothing.
  - Pose from depth: stable to ~2 mm; size 129–135 × 91–102 mm (a standard plate is 128 × 86 mm).
  - Detection time: 33 ms with CLAHE (6 ms of it).
  - `camera_perception/test/data/zedx_clear_plate.jpg` keeps one of these frames as a regression test.
- **Not covered by these checks:** a live ACT rollout on the xArm.

## Not included

These parts are not included, and the originals remain in the repo root:
- teleoperation, SpaceMouse and recording
- the web UI
- the Camera-Edge source
- training and dataset conversion
- the `--dry-run` and `--no-depth` rollout modes

## TODO

- `package.xml` of the four ROS packages still says `TODO: License declaration`.
- The vendored code keeps its own licenses:
  - `act_inference/act_inference/act/LICENSE` (MIT)
  - `act_inference/act_inference/act/detr/LICENSE` (Apache-2.0)
  - `zedx_nano_depth/zedx_nano_depth/raft_stereo/LICENSE` (MIT)

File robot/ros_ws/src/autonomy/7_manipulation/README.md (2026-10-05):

# 7_manipulation: visual servo grasp and live ACT inference

| folder | what it is | needs |
|---|---|---|
| `visual_servoing/` | ROS 2 package (`ament_python`). Wrist-camera (ZED X Nano) visual servo grasp of a well plate on the xArm6: YOLO oriented boxes located with the stereo depth, a position-based servo to a hover pose above the plate, then the descend / FSR close / lift sequence of the Xavier's Camera-Edge. Serves the Camera-Edge control WebSocket that `6_behavior/manipulation_executive` drives | `3_perception`'s `camera_perception` and `zedx_nano_depth` (as libraries), a running camera stack; pip: `xarm-python-sdk`, `websockets`, `ultralytics` (torch) |
| `act_inference/` | **Not** a ROS package (`COLCON_IGNORE`): plain Python. Live ACT rollout on the xArm6 from the wrist camera, with a trimmed copy of the ACT/DETR model code | `3_perception`'s `zedx_nano_camera` and `zedx_nano_depth` (as libraries); torch, xArm SDK |

Both folders are shared with the `apple_server_manip` repo (`2_manipulation/`), where they are developed and
where the full documentation lives — `2_manipulation/README.md` has the mount model, the measurements behind it
and what has and has not been verified on the arm. The copies are identical except that this one
takes the YOLO weights from `camera_perception`'s package share, as the rest of this workspace does:
`yolo_models_dir` defaults to `$(find-pkg-share camera_perception)/models/yolo`. Port changes both ways.

## Where this fits in the stack

```
3_perception (camera hub, /zedx_nano image + depth)
        │
        ▼
visual_servoing  ──ws://<host>:8765──►  6_behavior/manipulation_executive
   /visual_servo/{start,stop,status,annotated_image}        (behavior tree)
        │
        ▼  xArm SDK (mode 5 velocity), next to xarm_ros2
      xArm6
```

`manipulation_executive` sends `{"cmd": "mode", "mode": "inspect"|"servo"}` and polls `{"cmd": "status"}` for
`{"mode": ..., "worker_alive": ...}`; `visual_servoing/edge_control.py` answers exactly that, so the executive
needs no change — **except its host**: `manipulation_executive.launch.xml` still has
`camera_edge_host = 192.168.1.101`, the Xavier's old Camera-Edge. Point it at whichever machine runs
`visual_servo_node` (the one with the GPU and the camera stack). The port stays 8765.

Nothing here is in `autonomy_bringup`, on purpose: this node can move the arm, so it is started by hand (or by
the behavior stack through the WebSocket) rather than with the rest of autonomy.

## Build

```bash
cd /home/robot/AutoLab/robot/ros_ws
colcon build --packages-select visual_servoing          # NOT `bws`: --symlink-install rewrites the node's
source install/setup.bash                               # shebang and loses the CUDA torch (see 3_perception)
pip install xarm-python-sdk websockets
pip install ultralytics --no-deps                       # as in 3_perception: plain install shadows the system cv2
```

`act_inference` is not built; it runs from this folder.

## Run the visual servo

The default is a **dry run**: the arm is only read, and the status shows the plate, the target and the velocity
the node would have commanded. The camera stack must be up and streaming the Nano (`3_perception`).

```bash
ros2 launch visual_servoing visual_servo.launch.xml                       # dry run
ros2 launch visual_servoing visual_servo.launch.xml execute:=true grasp:=false   # moves, stops at the hover pose
ros2 launch visual_servoing visual_servo.launch.xml execute:=true         # full grasp
ros2 service call /visual_servo/start std_srvs/srv/Trigger                # a run (or drive it over the WebSocket)
ros2 service call /visual_servo/stop std_srvs/srv/Trigger
```

| name | type | |
|---|---|---|
| `/visual_servo/start`, `/visual_servo/stop` | `std_srvs/Trigger` | start a run (returns at once) / abort it |
| `/visual_servo/status` | `std_msgs/String` | JSON at 2 Hz and at the end of a run (transient local): `phase`, `result`, `message`, `attempt`, `error_mm`, `error_yaw_deg`, `plate_mm`, `target_mm`, `start_tip_mm`, `command_mm_s`, `fsr`, `mode` |
| `/visual_servo/annotated_image` | `Image` bgr8 | wrist image with the plate box, the fingertip model and the state; published only while subscribed |
| `ws://0.0.0.0:8765/` | WebSocket | the Camera-Edge control protocol (`control_port:=-1` turns it off) |

Launch arguments: `execute` (false), `grasp` (true), `preview` (false), `robot_ip` (192.168.1.236),
`yolo_models_dir` + `model` (best_wrist.pt), `device` (cuda:0), `control_port` (8765), `params_file`
(`config/visual_servo.yaml`, every other parameter with comments), and `with_cameras` (false) with
`depth_models_dir` / `depth_repo` to start the camera stack too.

### Safety

- `execute:=false` is the default; the dry-run arm object refuses every motion call.
- Velocity commands carry a 0.25 s deadman, so a stalled loop stops the arm. The fingertips move at most
  20 mm/s and 0.3 rad/s; the descent slows to 8 mm/s near the plate.
- A target more than 250 mm from where the run started, a plate whose measured length is off by more than 35 %,
  or 5 s without a detection fails the run. Without a fresh detection for 0.5 s the arm holds still.
- Nothing else may command the arm during a run — `xarm_ros2` trajectories, ACT, teleop. Every run ends in
  mode 1, state 0, so `xarm_ros2` can take over again.
- **Before the first grasp on this workspace**, check the fingertip height with a dry run and then a hover-only
  run (`execute:=true grasp:=false`), as `2_manipulation/README.md` describes. The mount model was measured on
  the arm on 2026-09-22; the grasp itself has only been run in simulation and against recorded episodes.

## Run ACT inference

```bash
cd src/autonomy/7_manipulation/act_inference
python run_act_inference.py --ckpt-dir models/xarm_final_ckpt_placing              # prediction only
python run_act_inference.py --ckpt-dir models/xarm_final_ckpt_placing --execute    # moves the arm
python run_act_inference.py --ckpt-dir models/xarm_final_ckpt_placing --camera-source ros --ros-namespace /zedx_nano
```

`models/xarm_final_ckpt_placing/` is the well-plate placing policy (RGB + depth, wrist camera), copied from
`apple_server_manip/data/act_ckpts/xarm_final_ckpt_placing` (`config.pkl`, `dataset_stats.pkl`, `policy_best.ckpt`).

`--camera-source nano-stream` (default) talks to the camera hub directly and needs no ROS; `--camera-source ros`
reads the camera stack's topics and needs a sourced workspace. `--help` lists the rest (rate, speed limits,
workspace radius, depth backend and model).

## Tests

No hardware: a synthetic camera, a stub robot and a stand-in for `ros2 launch`.

```bash
export ROS_DOMAIN_ID=73 ROS_AUTOMATIC_DISCOVERY_RANGE=LOCALHOST   # keep test traffic off the robot network
python -m pytest visual_servoing/test act_inference/tests -q      # 85 tests
```

They need `rclpy`, `cv_bridge`, numpy, OpenCV, torch and the `3_perception` sources, which the tests find
either next to this folder or in the sibling group folder — no build required.

## Not done here yet

- These packages were written and tested on **Jazzy**. The source has no version-specific syntax and the tests
  pass on this machine; on Humble only the control WebSocket needed a fix so far (this container's
  `websockets` ≥ 14 wants `serve()` called inside the event loop), and nothing beyond node startup has
  been exercised here yet.
- The first on-arm grasp (fingertip check above).
- `manipulation_executive`'s `camera_edge_host` still points at the Xavier.

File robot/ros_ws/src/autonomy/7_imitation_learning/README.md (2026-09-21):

# 7_imitation_learning: ACT data collection + training for placing a wellplate

Not a ROS package (`COLCON_IGNORE` is present): plain Python with its own venv, so colcon skips it.

```
collect.sh            collect demonstrations (keyboard teleop, keep/delete each one)
inspect.sh            check an episode / list a dataset
view.sh               web viewer: both cameras + depth + joint angles for saved episodes (collect.sh starts it too)
configs/collect.yaml  IPs, stream size, speeds, workspace box, start pose
actlib/               collect.py keyboard_teleop.py arm_io.py cam_client.py episode_io.py inspect_episode.py
xavier/               record_worker.py + PATCH.md/PATCH.diff: what was added to the Xavier camera server
data/  runs/  .venv/  git-ignored: datasets, training runs, virtualenv
```

## Collect (arm side)

Before the first run:
1. **Check `workspace_mm` in `configs/collect.yaml`** for your deck. z min is the table clearance (now 70 mm): keep the fingertips above it.
2. The Xavier camera server must be the patched one (it has record mode; see `xavier/PATCH.md`).
3. Hand on the e-stop. Keys are read **globally** (any window) while jogging/recording.

**Planning stack:** it can keep running. The xArm ROS driver (`ros2 launch planning_bringup ...`) pauses its own controllers while the arm
is in this script's velocity mode and reactivates them when the arm is back in servo mode 1. This script owns the arm (and puts the
Xavier in record mode) **only while you jog or record**; after every jog and every episode it hands the arm back (mode 1 when the ROS
driver is running, else the mode it found) and returns the Xavier to its normal mode, so planning and perception work between episodes.
Do not send planning commands during a jog or recording: one arm, one commander. Only `servo.py` (leader teleop) and
`joy_cartesian_jog.py` block startup.

```bash
./collect.sh --dataset wellplate_place --target 40     # resumable: counts episodes already on disk
```

Per episode: `Enter` starts recording -> drive with the keys -> `Enter` finishes -> `k` keep / `d` delete.
A deleted episode never touches the disk. `j` at the first prompt jogs the arm without recording; `g` goes to `start_pose` (if set).

| key | action |
|---|---|
| W / S | +X / -X (base frame) |
| A / D | +Y / -Y |
| R / F | +Z / -Z |
| Q / E | rotate the last joint +/- (angular velocity about base +Z; tool stays vertical) |
| 1 / 2 / 3 | speed preset: 15 / 40 / 100 mm/s and 8 / 20 / 45 deg/s (starts on 2; edit `teleop.presets`) |
| Enter | finish (ramps to zero first) |
| Esc | stop immediately and discard the episode |

Hold to move, release to stop. Velocity is slewed (250 mm/s^2, 150 deg/s^2), the command loop runs at 100 Hz, and the TCP is kept
inside the workspace box. If the controller faults (e.g. near a singularity) it is re-armed automatically and the event is stored.

## What is recorded

| stream | rate | notes |
|---|---|---|
| wrist camera left + right | ~29 Hz | JPEG, 640x400 (default), stamped at capture on the Xavier. **Duplicate frames are removed at save time** (below) |
| depth (aligned to left) | ~29 Hz | PNG16, uint16 mm, 0 = invalid, lossless |
| joints, TCP pose, joint torque | ~99 Hz | controller real-time report (port 30003) |
| commanded velocity + raw key intent | 100 Hz | |
| gripper setpoint + 2 finger pressure sensors | ~5 Hz | state only |
| aligned/ | at each camera frame | robot state interpolated to the frame's capture time: what training reads |

```
data/<dataset>/dataset.yaml   conventions, units, camera calibration
data/<dataset>/index.csv      table of the episode files, REBUILT from them (never edit it: to delete an episode just delete its .hdf5)
data/<dataset>/episodes/episode_0001.hdf5 ...   (layout in actlib/episode_io.py)
data/<dataset>/sessions/*.log console log of every session, including discarded attempts
```
**Duplicate frames:** a camera frame is dropped when its joint angles are exactly the same as the previous frame's. Joint angles only:
no tolerance, and neither the picture nor the timestamps are compared. The first frame of each still stretch is kept. A waiting arm that
is exactly still reports bit-identical angles (in a first real episode 67% of consecutive frame pairs were), so those frames go; frames
where the angles differ even in the 4th decimal (sensor jitter, slow creep) are different frames and stay. Frames where only the scene or
the gripper changes while the arm is still are dropped too. The waiting at the END of a recording (after the last kept frame) is also cut
from the saved robot / control / gripper logs, so the saved episode ends where its frames end. The 100 Hz robot log is otherwise never
thinned. Kept frames are therefore not evenly spaced: `frames/t` has each one's true capture time and the
`stat_*` attributes / `index.csv` still describe the health of the full recorded stream. Disable in `recording.dedupe`.

Clock handling: the Xavier and this machine are NTP-synced yet differ by tens of ms and drift ~1 ms/min, so the offset is measured
(20 round trips, best RTT) before and after every episode and stored; `frames/t` is already corrected (verified to <1 ms).

**Deleting an episode:** delete its file `episodes/episode_000N.hdf5` and nothing else. `index.csv` is rebuilt from the files at every
start and save and re-checked every 2 s while `collect.sh` runs (`./inspect.sh <dataset>` always reads the files directly), so the row
disappears by itself and a re-recorded number never appears twice. Deleting in VS Code sends the file to the Trash (still on disk);
`rm` deletes it for good.

Watch saved episodes in a browser (left + right camera + colourised depth + joint angles / TCP / commanded velocity / gripper, all on
one timeline; play, step, scrub, click a plot to seek, 0.25x-2x):
```bash
./collect.sh ...        # starts the viewer automatically and prints http://localhost:8090/?episode=N after every save
./view.sh               # or run it on its own for any dataset: ./view.sh data/wellplate_place --port 8090
```
Keys in the page: space play/pause, left/right step one frame, shift+left/right +-1 s, [ ] previous/next episode.
It is read-only and runs as its own process (it cannot slow the control loop). `--host 0.0.0.0` opens it to other machines.

Inspect from the terminal:
```bash
./inspect.sh data/wellplate_place                       # list + totals
./inspect.sh data/wellplate_place/episodes/episode_0001.hdf5 --montage m.png --plot p.png --video v.mp4
```

## Known limits
* **The Xavier's Ethernet negotiated 100 Mb/s** (the Thor side is 1 Gb/s): probably a cable or switch port. That caps the wire at
  ~11.8 MB/s, hence 640x400. With a gigabit link set `xavier.scale: 1.0`, `jpeg_quality: 95` in `configs/collect.yaml`.
* Depth is NEURAL from a stereo pair: invalid on ~11% of pixels (very close / reflective / edges).
* `duration=0` velocity commands have no firmware watchdog: a `kill -9` of the collector while moving leaves the arm moving.
  Ctrl-C / Esc / exceptions all zero the velocity. Keep the e-stop in reach.

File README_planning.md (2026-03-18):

Notes by Karthik:

Source files:
Planning code: Autolab/robot/ros_ws/src/autonomy/global_planner/src
Robot urdf: Autolab/robot/ros_ws/src/base_urdf
Moveit_Config files: Autolab/robot/ros_ws/src/base_moveit_config_2

Motion planning using RViz (ROS2 Humble + Moveit)
Steps to run the code
1. cd Autolab - go into the folder
2. autolab up robot - just fire up the robot docker in case you want to run only motion planning in RViz and no isaac sim. In case you want to run IsaacSim as well, then just run autolab up
3. Go into the docker - autolab connect robot. It should go into the ros_ws folder inside the docker.
4. build the packages (ignore 2 packages that give errors but are irrelevant for now) - colcon build --packages-ignore robot_bringup rviz_behavior_tree_panel
5. source install/setup.bash - ignore the robot_bringup warning
6. ros2 launch global_planner move_and_rviz.launch.py - This will open RViz, load the robot and execute the motion planning algorithms for a hardcoded pose and environment.

Functions of the code

    1. add_collision_table: Injects a static 3D box into the MoveIt scene to represent the work surface and prevent base collisions.
    2. saveTrajectoryToFile: Exports time-stamped joint positions to a .txt file for external logging or simulation replay.
    3. make_ee_down_constraint:Defines an orientation constraint that forces the end-effector to point vertically downward during motion.
    4. make_path_marker:	Uses Forward Kinematics (FK) to convert joint-space trajectories into 3D line markers for RViz visualization.
    5. plan_and_publish_rrt:	Stage 1 (Global): Uses OMPL (RRT*) to find a collision-free geometric path to a Cartesian target.
    6. plan_and_publish_chomp:	Stage 2 (Local): Smooths the RRT* path using gradient descent to minimize jerky joint movements.
    7. add_hollow_point_cloud_obstacle: Procedurally generates a 5-sided "safety box" made of spheres if live camera data is unavailable.

Flow of the code

    Initialization: Sets up MoveGroupInterface for the arm and gripper, and launches a background thread for the ROS 2 executor.

    Static Environment Setup: Adds a fixed collision table to the MoveIt Planning Scene to prevent base/floor collisions.

    Perception Sync: Waits up to 5 seconds for a live /perception/obstacle_pointcloud.

    Safety Fallback: If no live cloud arrives, it procedurally generates a Hollow 5-sided Box (Point Cloud Obstacle) to define a safe workspace.

    Target Acquisition: Retrieves the goal pose from the /perception/target_pose topic or falls back to hard-coded defaults.

    Stage 1 - Global Planning (RRT):*

        Validates target reachability via Inverse Kinematics (IK).

        Generates a collision-free geometric path while maintaining a Z-down orientation constraint.

        Executes the arm motion and publishes a Green Path marker to RViz.

        Synchronization: Pauses for 500ms post-execution to allow the Planning Scene to update the robot's current state.

    Stage 2 - Local Optimization (CHOMP) (only runs for Move, not for grasp):

        Reuses the RRT* end-state as a joint-space goal.

        Optimizes the trajectory for smoothness, minimizing jerky movements.

        Publishes a Blue Path marker to RViz.

    Task Finalization:

        If "Move": Completes the smoothed trajectory.

        If "Grasp": Actuates the gripper sliders to the live_grasp_width using gripper_group.move().

        Data Logging: Saves the final time-stamped joint trajectories to .txt files for analysis
        
Additional code to run integration with isaac-sim 

sudo apt update
sudo apt install ros-humble-topic-based-ros2-control

ros2 run controller_manager ros2_control_node --ros-args -p use_sim_time:=True

# Check if controller is running
ros2 control list_controllers
Should output

# Check live ee pose
ros2 run tf2_ros tf2_echo world end_effector_p4_1

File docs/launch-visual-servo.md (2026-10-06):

# Launch visual servoing — from scratch

The grasp runs on the Xavier (`~/Autolab-Camera-Edge/visual_servo.py`) and drives the arm directly over the xArm SDK. Before starting:

- gripper mounted and its RS-485 cable connected
- on the Xavier, `~/Autolab-Camera-Edge/config.py` has `DEBUG = False` (with `True` nothing moves)
- nothing else executing on the arm (the planning stack may be up, but idle)
- a well plate under the wrist camera, e-stop in reach

## 1–2. Network + camera server

Same as [launch-planning.md](launch-planning.md) steps 1–2.

## 3. Watch the wrist camera (optional)

```bash
ssh autolab@192.168.1.101 'cd ~/Autolab-Camera-Edge/example_client && python3 -m http.server 8080'
# Firefox → http://192.168.1.101:8080/test.html → host 192.168.1.101 → Connect → Wrist tile
```

## 4a. Trigger directly (Jetson)

```bash
/usr/bin/python3 ~/coding/percep/test_server.py ws://192.168.1.101:8765
> servo        # arm → start pose, gripper opens, servos down onto the plate, closes on FSR contact, lifts
> status       # worker_alive=false when finished
> stop         # abort at any time
> idle
```

## 4b. Trigger through the pipeline (Jetson)

Planning stack up ([launch-planning.md](launch-planning.md) step 4), then the executives:

```bash
docker exec -it autolab-robot-l4t-1 bash -lc 'export ROS_LOCALHOST_ONLY=1 FASTRTPS_DEFAULT_PROFILES_FILE=/home/robot/AutoLab/common/ros_packages/fastdds_loopback.xml; ros2 launch behavior_bringup behavior.launch.xml'
```

`behavior_tree_msgs` exists only inside the container, so these two run there:

```bash
docker exec -it autolab-robot-l4t-1 bash -lc "export ROS_LOCALHOST_ONLY=1 FASTRTPS_DEFAULT_PROFILES_FILE=/home/robot/AutoLab/common/ros_packages/fastdds_loopback.xml; ros2 topic echo /robot_1/behavior/manipulation_phase"
docker exec autolab-robot-l4t-1 bash -lc "export ROS_LOCALHOST_ONLY=1 FASTRTPS_DEFAULT_PROFILES_FILE=/home/robot/AutoLab/common/ros_packages/fastdds_loopback.xml; ros2 topic pub --once /robot_1/behavior/manipulation_command behavior_tree_msgs/msg/ManipulationCommand '{type: pick_base, object_type: well_plate, target_machine: \"\"}'"
# sequence: inspect → plan above the plate → servo grasp → plan_home_offset
# SUCCESS is reported when the Xavier's worker goes idle, whether or not a plate was grasped
```

## 5. Afterwards

Send `plan_home_offset` ([launch-planning.md](launch-planning.md) step 5). If the next plan won't execute, restart the planning launch.

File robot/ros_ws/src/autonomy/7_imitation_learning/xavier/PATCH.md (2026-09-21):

# Xavier changes for record mode (2026-09-18)

Machine: the AGX Xavier camera box (`autolab@192.168.1.101`), project `~/Autolab-Camera-Edge/`.
The full edit is in [PATCH.diff](PATCH.diff) (applied to the files exactly as they were that day); the new file is
[record_worker.py](record_worker.py) (copy it to the Xavier next to `main.py`).

## What it adds
* **Record mode** (`{"cmd":"mode","mode":"record"}` on :8765): the wrist ZED X is grabbed with depth on and streamed as
  binary frames on **:8768**: `[u32 LE header_len][JSON header][left JPEG][right JPEG][depth PNG16, uint16 mm, 0 = invalid]`.
  Frames are stamped at capture. Images/depth are downscaled on the Xavier (`RECORD_SCALE`, default 0.6667 = 640x400)
  because the Xavier's Ethernet link negotiated only 100 Mb/s (`cat /sys/class/net/eth0/speed` -> 100).
* Control port commands: `time` (Xavier clock, for the clock probe), `record_config` (`scale`, `jpeg_quality`, applied per session
  by `collect.py`), and `status` now reports `record_available`.
* `config.py`: `RECORD_PORT`, `RECORD_SCALE`, `RECORD_JPEG_QUALITY`, `WRIST_DEPTH_MODE` (`NEURAL`), `WRIST_DEPTH_MIN_MM/MAX_MM` (-1 = SDK default).

## Behaviour changes to know about
* The wrist camera is now **opened with NEURAL depth**. Depth is only computed while record mode runs: `image_worker.py` and
  `visual_servo.py` set `enable_depth = False` on their grabs, so idle / servo behave as before.
* While record mode is active the idle worker does **not** grab the wrist camera (otherwise the two threads split the frames);
  the GCS `wrist_raw` tile is fed from the record worker at ~5 Hz. Inspect / servo modes are off while recording.
  `collect.py` restores the previous mode when it exits.

## How it is running now
Started by hand in tmux (not by systemd): `tmux attach -t camera_edge` (log: `~/camera_edge_20260918.log`).
The original service `autolab-camera-edge.service` was stopped with SIGINT (clean exit, systemd did not respawn it).

## Hand back to systemd (needs the Xavier sudo password)
```bash
tmux kill-session -t camera_edge        # or Ctrl-C in the pane
sudo systemctl start autolab-camera-edge
```
The service runs the same files, so it will come up with record mode included.

## Roll back
Originals were saved next to the files as `*.bak-20260918` (`main.py config.py image_worker.py visual_servo.py`):
```bash
cd ~/Autolab-Camera-Edge && for f in main.py config.py image_worker.py visual_servo.py; do cp -p $f.bak-20260918 $f; done
rm record_worker.py     # then restart as above
```

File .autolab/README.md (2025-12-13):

# Autolab CLI Tool

The `autolab` command-line tool provides a unified interface for common development tasks in the Autolab project, including setup, installation, and container management.

## Installation

The `autolab` tool is included in the Autolab repository. To set it up:

1. Clone the Autolab repository:
   ```bash
   git clone https://github.com/arker123/Autolab
   cd Autolab
   ```

2. Run the setup command:
   ```bash
   ./autolab setup
   ```

This will add the `autolab` command to your PATH by modifying your shell profile (`.bashrc` or `.zshrc`).

## Basic Usage

```bash
autolab <command> [options]
```

To see all available commands:
```bash
autolab commands
```

To get help for a specific command:
```bash
autolab help <command>
```

## Core Commands

- `install`: Install dependencies (Docker Engine, Docker Compose, etc.)
- `setup`: Configure AutoLab settings and add to shell profile
- `up [service]`: Start services using Docker Compose
- `stop [service]`: Stop services
- `connect [container]`: Connect to a running container (supports partial name matching)
- `status`: Show status of all containers
- `logs [container]`: View logs for a container (supports partial name matching)

### Container Name Matching

The `connect` and `logs` commands support partial name matching for container names. This means you can:

1. Use just a portion of the container name (e.g., `autolab connect web` will match `autolab_web_1`)
2. If multiple containers match, you'll be shown a list and prompted to select one
3. The matching is case-insensitive and supports fuzzy matching

Example:
```bash
$ autolab connect web
[WARN] Multiple containers match 'web'. Please be more specific or select from the list below:
NUM     CONTAINER NAME  IMAGE   STATUS
1       autolab_web_1  nginx:latest    Up 2 hours
2       autolab_webapi_1       node:14 Up 2 hours

Options:
  1. Enter a number to select a container
  2. Type 'q' to quit
  3. Press Ctrl+C to cancel and try again with a more specific name

Your selection: 1
[INFO] Connecting to container: autolab_web_1
[INFO] Tip: Next time, you can directly use 'autolab connect autolab_web_1' for this container
```

## Development Commands

- `test`: Run tests
- `docs`: Build documentation
- `lint`: Lint code
- `format`: Format code

## Extending the Tool

The `autolab` tool is designed to be easily extensible. You can add new commands by creating module files in the `.autolab/modules/` directory.

### Creating a New Module

1. Create a new `.sh` file in the `.autolab/modules/` directory:
   ```bash
   touch .autolab/modules/mymodule.sh
   ```

2. Add your command functions and register them:
   ```bash
   #!/usr/bin/env bash

   # Function to implement your command
   function cmd_mymodule_mycommand {
       log_info "Running my command..."
       # Your command implementation here
   }

   # Register commands from this module
   function register_mymodule_commands {
       COMMANDS["mycommand"]="cmd_mymodule_mycommand"
       COMMAND_HELP["mycommand"]="Description of my command"
   }
   ```

3. Make the module executable:
   ```bash
   chmod +x .autolab/modules/mymodule.sh
   ```

Your new command will be automatically loaded and available as `autolab mycommand`.

### Available Helper Functions

When creating modules, you can use these helper functions:

- `log_info "message"`: Print an info message
- `log_warn "message"`: Print a warning message
- `log_error "message"`: Print an error message
- `check_docker`: Check if Docker is installed and running

## Configuration

The `autolab` tool stores its configuration in `~/.autolab.conf`. This file is created when you run `autolab setup`.

## License

This tool is part of the AutoLab project and is subject to the same license terms.

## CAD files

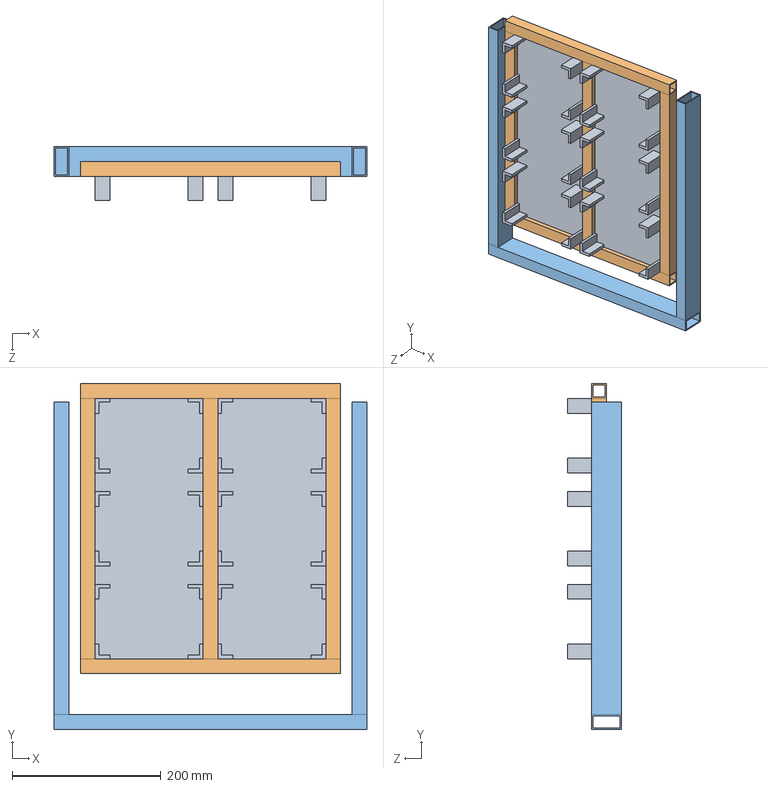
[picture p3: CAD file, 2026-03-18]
simulation/isaac-sim/Shaker_Assembly.STEP
420.0 x 465.0 x 72.0 mm
Shaker_2DSketch
T1_2x2 x 2
T2_2x2 x 3
T2_4x2 x 3

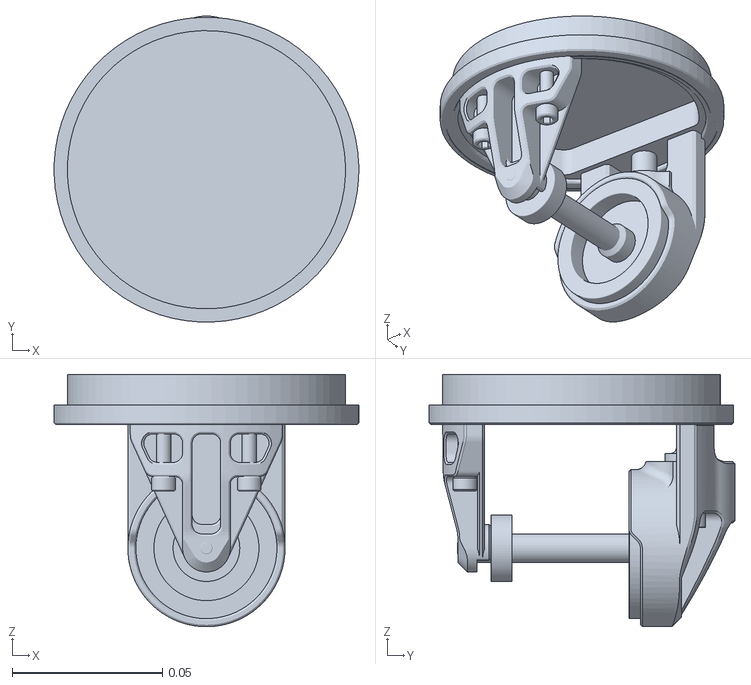
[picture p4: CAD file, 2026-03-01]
robot/ros_ws/src/autonomy/5_planning/base_urdf/meshes/Az_Front_right_1.stl
0.102 x 0.102 x 0.0841

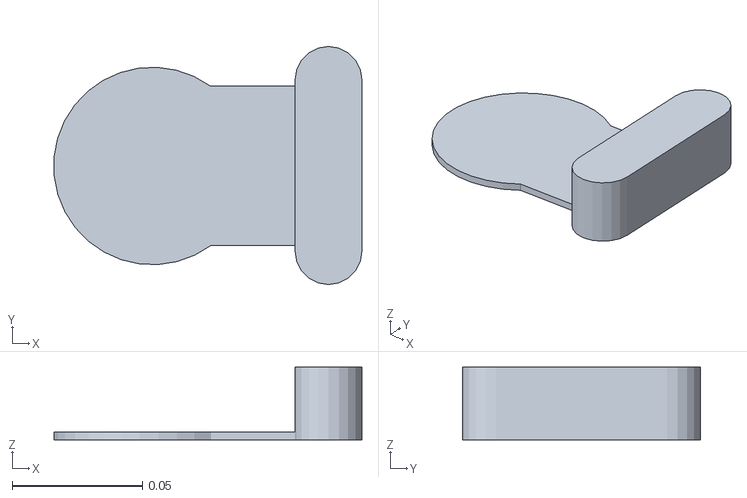
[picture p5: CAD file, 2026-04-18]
robot/ros_ws/src/autonomy/5_planning/xarm_ros2/xarm_description/meshes/camera/realsense/collision/d435_with_cam_stand.stl
0.118 x 0.0914 x 0.028

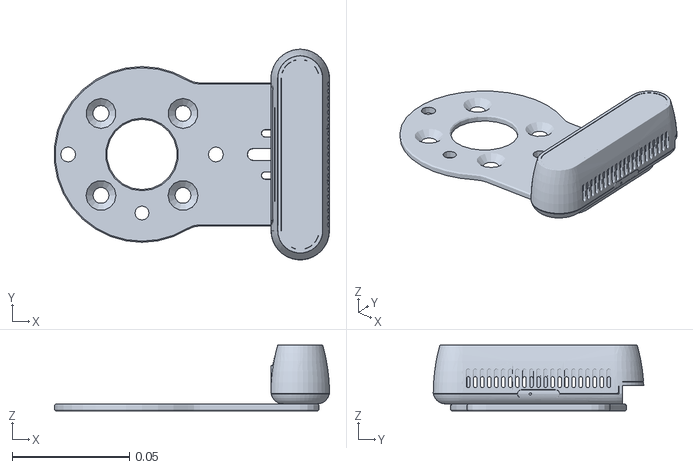
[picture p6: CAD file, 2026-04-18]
robot/ros_ws/src/autonomy/5_planning/xarm_ros2/xarm_description/meshes/camera/realsense/visual/d435_with_cam_stand.stl
0.117 x 0.0899 x 0.028

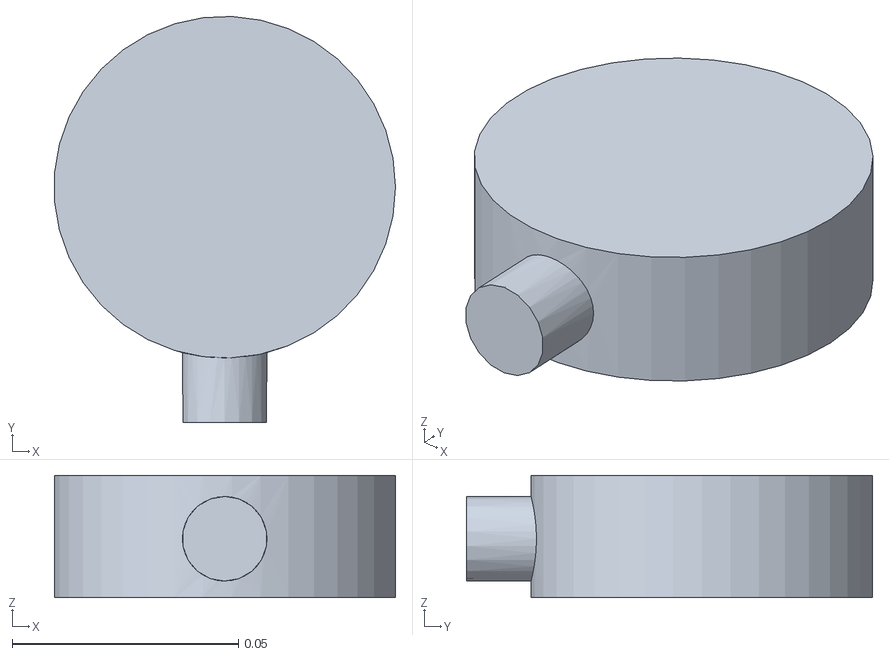
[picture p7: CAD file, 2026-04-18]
robot/ros_ws/src/autonomy/5_planning/xarm_ros2/xarm_description/meshes/end_tool/collision/end_tool.stl
0.0753 x 0.0897 x 0.027

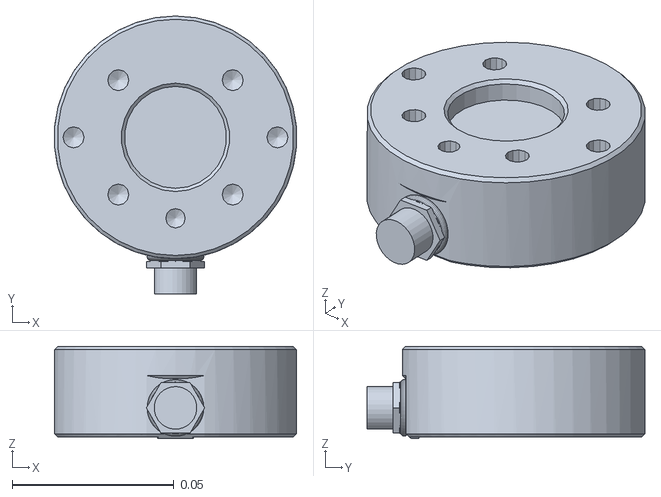
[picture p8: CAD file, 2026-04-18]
robot/ros_ws/src/autonomy/5_planning/xarm_ros2/xarm_description/meshes/end_tool/visual/end_tool_1300.stl
0.0749 x 0.0859 x 0.0285

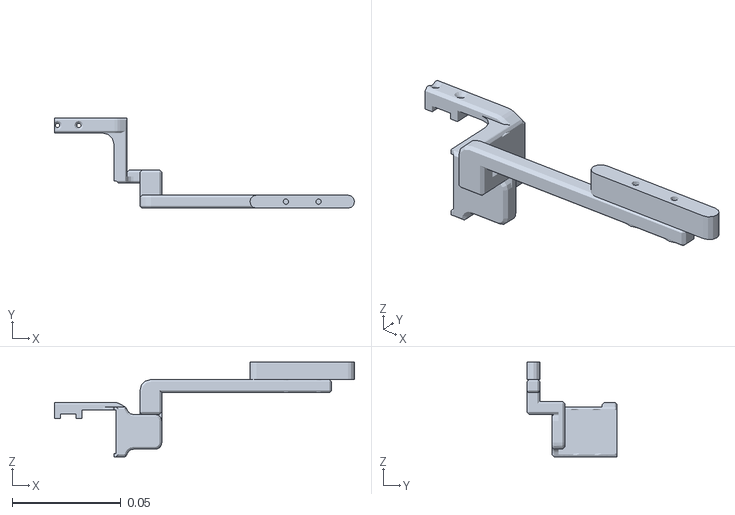
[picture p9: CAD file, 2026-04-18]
robot/ros_ws/src/autonomy/5_planning/xarm_ros2/xarm_description/meshes/gripper/bio/left_finger.stl
0.138 x 0.0415 x 0.0435

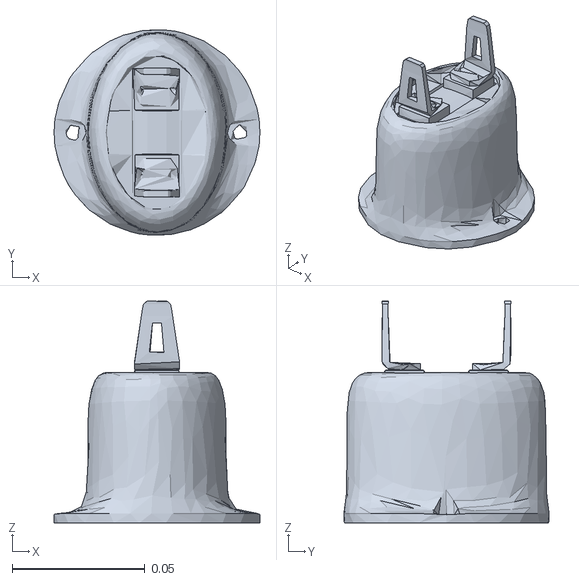
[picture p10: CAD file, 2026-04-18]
robot/ros_ws/src/autonomy/5_planning/xarm_ros2/xarm_description/meshes/gripper/lite/collision/gripper_lite.stl
0.0775 x 0.0773 x 0.0835

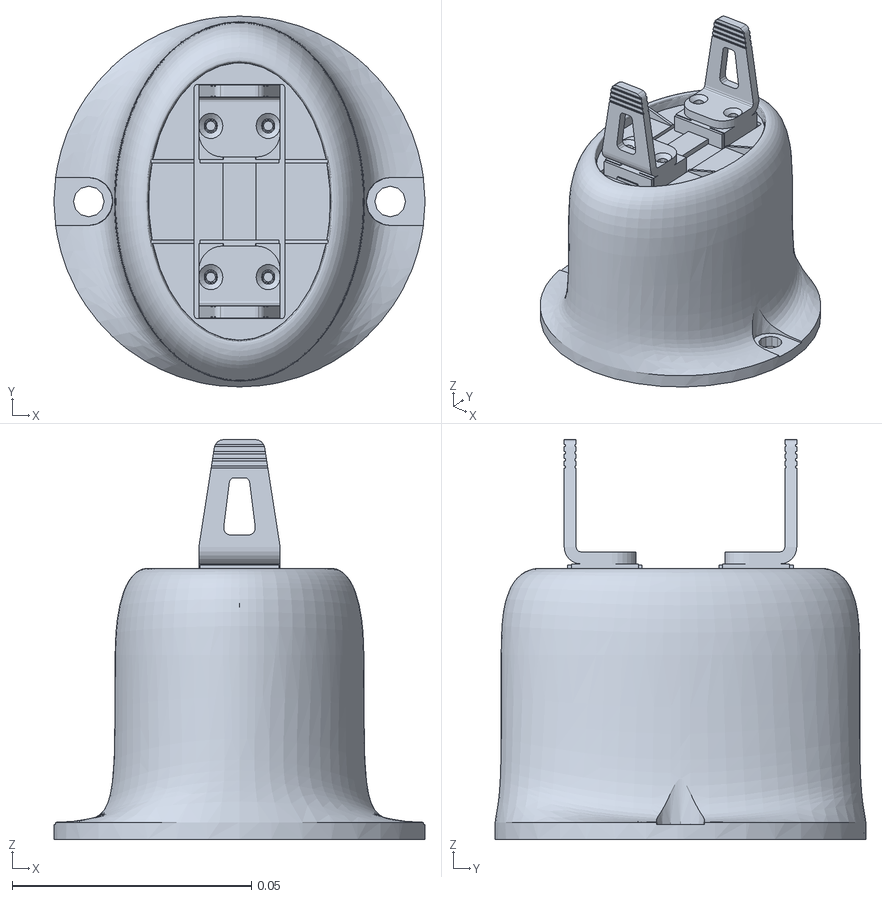
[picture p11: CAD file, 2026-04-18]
robot/ros_ws/src/autonomy/5_planning/xarm_ros2/xarm_description/meshes/gripper/lite/visual/gripper_lite.stl
0.0775 x 0.0775 x 0.0836

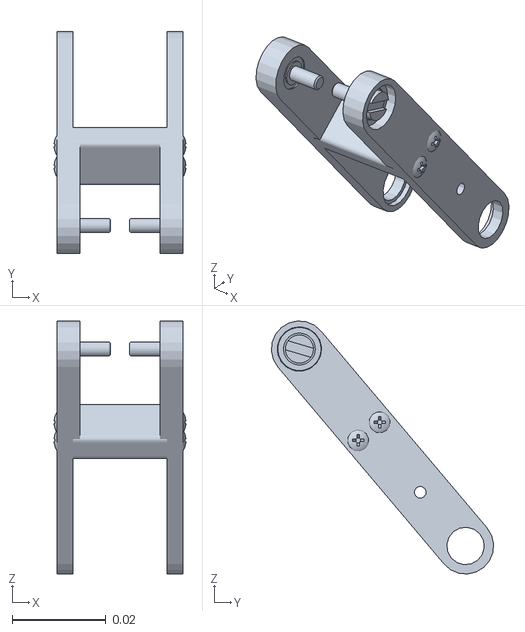
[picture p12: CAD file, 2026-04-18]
robot/ros_ws/src/autonomy/5_planning/xarm_ros2/xarm_description/meshes/gripper/xarm/right_inner_knuckle.stl
0.0281 x 0.0474 x 0.054

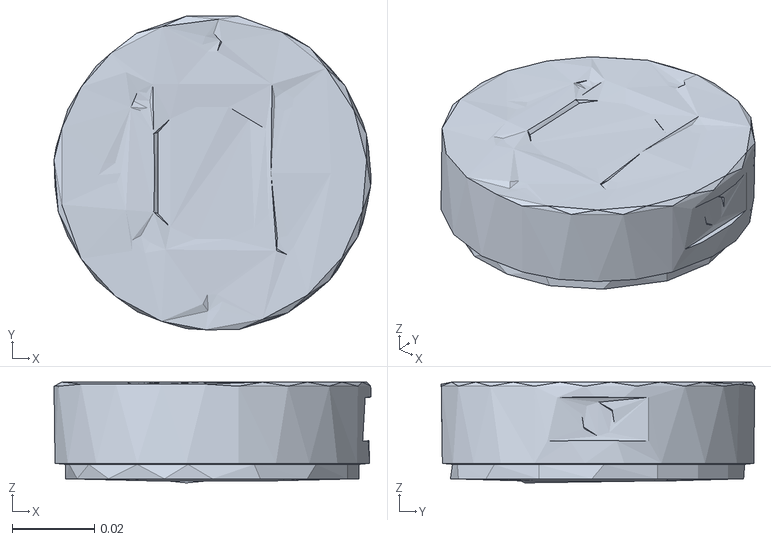
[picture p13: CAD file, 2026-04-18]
robot/ros_ws/src/autonomy/5_planning/xarm_ros2/xarm_description/meshes/lite6/collision/link6.stl
0.077 x 0.0762 x 0.0245

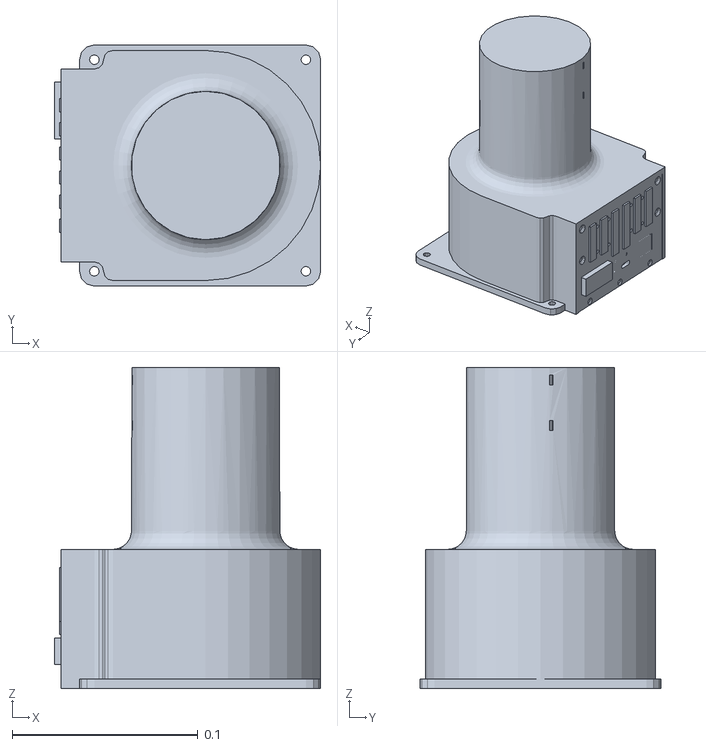
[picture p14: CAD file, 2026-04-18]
robot/ros_ws/src/autonomy/5_planning/xarm_ros2/xarm_description/meshes/lite6/visual/link_base.stl
0.144 x 0.13 x 0.173

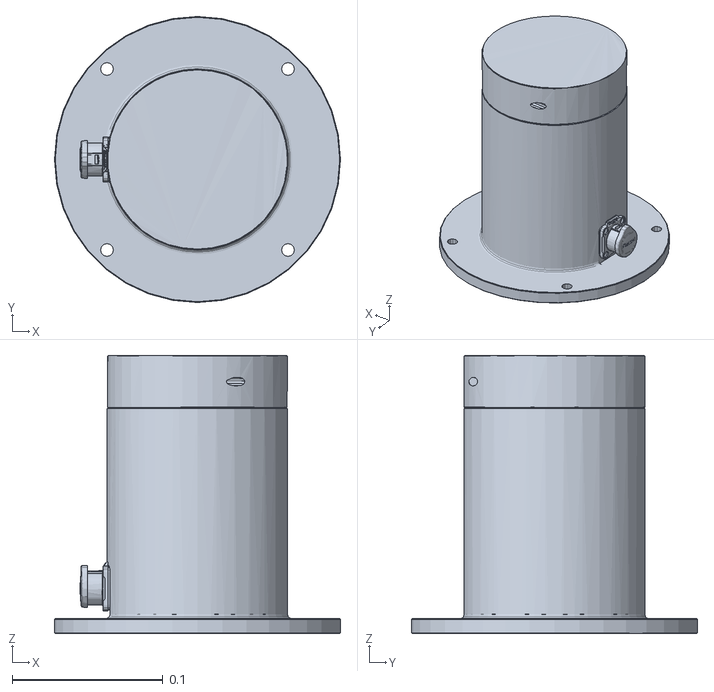
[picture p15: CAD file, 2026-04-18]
robot/ros_ws/src/autonomy/5_planning/xarm_ros2/xarm_description/meshes/uf850/collision/link_base.stl
0.19 x 0.19 x 0.185

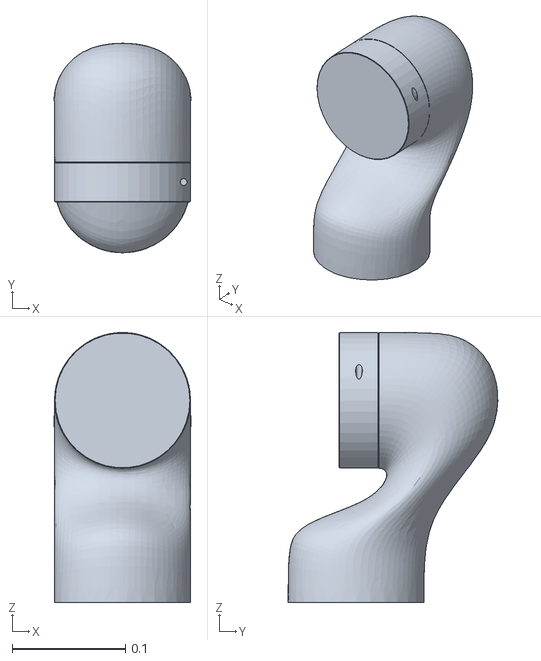
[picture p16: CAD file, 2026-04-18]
robot/ros_ws/src/autonomy/5_planning/xarm_ros2/xarm_description/meshes/uf850/visual/link1.stl
0.121 x 0.185 x 0.238

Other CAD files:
robot/ros_ws/src/autonomy/5_planning/xarm_ros2/xarm_description/meshes/vacuum_gripper/lite/collision/vacuum_gripper_lite.stl
robot/ros_ws/src/autonomy/5_planning/xarm_ros2/xarm_description/meshes/vacuum_gripper/lite/visual/vacuum_gripper_lite.stl
robot/ros_ws/src/autonomy/5_planning/xarm_ros2/xarm_description/meshes/vacuum_gripper/xarm/collision/vacuum_gripper.stl
robot/ros_ws/src/autonomy/5_planning/xarm_ros2/xarm_description/meshes/vacuum_gripper/xarm/visual/vacuum_gripper.stl
robot/ros_ws/src/autonomy/5_planning/base_urdf/meshes/Az_Back_Right_1.stl
robot/ros_ws/src/autonomy/5_planning/base_urdf/meshes/Az_Back_left_1.stl
robot/ros_ws/src/autonomy/5_planning/base_urdf/meshes/Az_Front_Left_1.stl
robot/ros_ws/src/autonomy/5_planning/base_urdf/meshes/Chasis_1.stl
robot/ros_ws/src/autonomy/5_planning/base_urdf/meshes/Chassis_1.stl
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

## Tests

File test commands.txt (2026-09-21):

ros2 topic pub --once /behavior/lab_machine_command behavior_tree_msgs/msg/LabMachineCommand "{device: 'ot2', action: 'protocol', parameters_json: '{\"steps\": [{\"action\": \"pick_up_tips\", \"resource_name\": \"tip_rack\", \"well_indices\": [0]}, {\"action\": \"aspirate\", \"resource_name\": \"tube_rack\", \"well_indices\": [0], \"volumes\": [50]}, {\"action\": \"dispense\", \"resource_name\": \"empty_plate\", \"well_indices\": [0, 1, 2, 3, 4], \"volumes\": [10, 10, 10, 10, 10]}, {\"action\": \"return_tips\"}]}'}"

ros2 topic pub --once /behavior/lab_machine_command behavior_tree_msgs/msg/LabMachineCommand  "{device: 'shaker', action: 'protocol', parameters_json: '{\"pwm\": 100}'}"

ros2 topic pub --once /behavior/manipulation_lab_command behavior_tree_msgs/msg/ManipulationCommand "{'type': 'pick_up', 'object_type': 'well_plate', 'target_machine': ''}"

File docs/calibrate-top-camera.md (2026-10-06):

# Calibrate the base camera (`top_camera`)

The base ZED's pose is six hardcoded numbers in
[`_robot_moveit_realmove.launch.py`](../robot/ros_ws/src/autonomy/5_planning/xarm_ros2/xarm_moveit_config/launch/_robot_moveit_realmove.launch.py)
(~line 227). Nothing in the repo produced them and nothing checks them. When the
point cloud in RViz sits at an angle to the real world, or plans aim beside the
target rather than at it, these are the numbers that are wrong.

`calibrate_top_camera.py` measures them. Tape an AprilTag to the gripper, move
the arm to a dozen poses, and for each pose two independent readings of the same
point exist: where the camera sees the tag, and where forward kinematics says the
gripper is. The transform that reconciles all of them is the calibration.

    X . A_i = B_i . Y

    X    Chassis_1 -> top_camera           what we want
    A_i  top_camera -> tag                 camera, via solvePnP
    B_i  Chassis_1 -> end_effector_p4_1    TF
    Y    end_effector_p4_1 -> tag          where the tag sits on the gripper

`Y` is solved for, not measured — **you do not need to place the tag anywhere in
particular or know its offset.** 12 unknowns, 6 equations per pose: 3 poses is the
theoretical minimum, ~12 is what actually works.

Hand-tuning these numbers instead is a trap: `world -> Chassis_1` carries a 180°
pitch flip ([`robot.urdf`](../robot/ros_ws/src/autonomy/5_planning/base_urdf/robot.urdf) ~line 298),
so `Chassis_1`'s +Z points **down** and every sign is inverted from what you expect.

## 1. Print the tag

`tag36h11`, **id 1**, black border exactly **62.5 mm**, with white quiet zone at
least one tag-cell wide left around it.

`inspect_cam.py` only reports ids 0, 1 and 2 (`if r.tag_id not in [0, 1, 2]`), so
the gripper tag has to be one of those three. **Exactly one tag with the chosen
id may be in frame** -- two tags sharing an id are indistinguishable, and
`capture` refuses the sample rather than guessing which is which.

The tag physically stuck on the OT-2 deck is **id 2** (confirmed from the
detector overlay, whatever `launch-planning.md` says about a shaker), so id 1 is
clear as long as no other id-1 tag is in view.

`plan_april_1` targets wherever tag 1 is currently seen, so while the tag is on
the gripper that command follows it and stops being meaningful.

**Measure the print with calipers before mounting it.** `apriltag_size_m = 0.0625`
is hardcoded in `inspect_cam.py` on the Xavier. "Fit to page" silently scales the
print, and a 5% scale error puts a 5% error into every translation the camera
reports. This is the most common way this calibration fails, and it fails
*quietly* — detection still works and the residuals still look small.

## 2. Mount it

Glue the tag to a **rigid flat card**, then attach the card to the gripper:

- **offset to one side, facing up and outward.** The camera is ~1.48 m above
  looking down, and the gripper's Z axis points down at the work, so anything on
  the underside is never seen. joint6 rolls about that same Z, so a tag centred
  on the axis barely moves when you roll — mounting it off-axis makes joint6
  sweep it through a wide arc, which is what pins down the rotation.
- **rigid.** `Y` is assumed identical for every pose. A tag that shifts mid-session
  makes the fit average the before and after instead of rejecting either — a
  confidently wrong answer with small-looking residuals.
- **flat.** `solvePnP` models the tag as a perfect plane; taped over a curved
  housing bakes in a bias.
- the card sticks out past the gripper — check it clears the workspace before
  jogging.

## 3. Bring the stack up

Planning stack running ([launch-planning.md](launch-planning.md) step 4; TF must
be live) and the camera in inspect mode (step 3). Verify from the Jetson:

```bash
ros2 run tf2_ros tf2_echo Chassis_1 end_effector_p4_1    # must update as the arm moves
```

## 4. Capture

```bash
cd ~/coding/Autolab && /usr/bin/python3 calibrate_top_camera.py capture
```

Jog the arm, let it come to a **full stop**, press ENTER. `u` undoes the last
sample, `q` finishes. Samples append to `top_camera_calib.json`, so you can stop
and resume.

Each sample averages 1.5 s of detections and is rejected if the tag position
sigma exceeds 4 mm — that rejection means the arm was still moving.

**Vary orientation aggressively, not just position.** Poses that differ only by
translation cannot observe the rotation at all: the fit will report a small
residual while being wrong. Roll and pitch the wrist differently on every pose.
Aim for 12+, spread across the workspace and across the camera's field of view.

## 5. Solve

```bash
/usr/bin/python3 calibrate_top_camera.py solve
```

**By default this fits the tag's position only and ignores its orientation.**
`solvePnP` recovers a planar tag's position well but its surface normal poorly,
and on a small tag that leaves a systematic several-degree error which no rigid
transform can absorb — it leaks into the answer while the translation residual
still looks fine. `--use-rotation` fits the full 6-DoF version; if its rotation
residual is more than ~2 deg mean, don't use the result.

Three things to read, in order of how much they matter:

- **leave-one-out stability** — refits with each sample removed in turn. This is
  the honest measure. Under ~3 mm and ~0.5 deg means the answer does not depend on
  which poses you happened to take. Large values mean the capture is
  under-constrained no matter how small the residual looks.
- **residual, before vs after** — a few mm is normal. Tens of mm means a bad tag
  print (step 1), a tag that moved (step 2), or too little orientation spread
  (step 4). Per-sample values are listed so you can delete an outlier and re-solve.
- **tag distance from the end effector** — compare against where you physically
  mounted it. If it's nonsense the fit is nonsense, whatever the residual says.

Duplicate arm poses are detected and called out; they add nothing to the fit.

Rotation error is amplified by distance: 0.5 deg is ~13 mm of lateral error out at
1.5 m. If you capture with the arm close to the camera, that is the accuracy you
are extrapolating to the working volume.

## 6. Apply

Paste the six printed numbers over the `arguments=[...]` list in
`_robot_moveit_realmove.launch.py` (~line 227; order is `x y z yaw pitch roll`),
then relaunch planning. It is a `static_transform_publisher`, so with
`--symlink-install` no rebuild is needed; if the old numbers persist:

```bash
docker exec autolab-robot-l4t-1 bash -lc 'cd ~/AutoLab/robot/ros_ws && colcon build --symlink-install --packages-select xarm_moveit_config'
```

Check it: re-run `pc3.py --fresh` and confirm in RViz that the table surface is
level and at the right height, and that the OT-2 deck lands where it physically is.

Commit the new numbers with the date and the residual the solve reported — it is
the only record that the calibration was ever done.

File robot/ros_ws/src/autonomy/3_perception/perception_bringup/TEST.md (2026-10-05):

# Testing `perception_bringup` (and the perception stack it launches)

This covers everything needed to build, unit-test, and smoke-test the perception stack on this repo's
Humble containers. It's a port of a stack originally built/tested on ROS 2 Jazzy (Python 3.12); the source
was audited for Jazzy-only syntax/API on 2026-09-22 (see `../README.md`) but had never actually been run
on Humble before that, so treat a first build here as unverified until you've done the steps below.

## 1. Start the container

```bash
autolab up robot
autolab connect robot
```

## 2. Build — do NOT use the `bws` shell alias

`bws` runs `colcon build --symlink-install`. That breaks `zedx_nano_camera`, `zedx_nano_depth`, `camera_ui`
and `camera_perception`: colcon rewrites their node scripts' shebang from `#!/usr/bin/env python3` to
`#!/usr/bin/python3`, which then runs the system Python (no CUDA torch) instead of whichever Python is
first on `PATH`. Build manually instead:

```bash
cd /home/robot/AutoLab/robot/ros_ws
colcon build --packages-select zedx_nano_camera zedx_nano_depth camera_ui camera_perception perception_bringup
source install/setup.bash
```

## 3. Install the Python deps `camera_perception` needs

The container already has `torch`, `torchvision`, `numpy`, `opencv-python` (global pip, no venv) and
`cv_bridge`/`python3-opencv` (from `ros-humble-desktop`). Missing: `pupil-apriltags` and `ultralytics`.

```bash
pip install pupil-apriltags
pip install --no-deps ultralytics 'filelock>=3.16.1' cloudpickle ultralytics-thop nvidia-ml-py
```

`--no-deps` is required on `ultralytics` — plain `pip install ultralytics` would reinstall `opencv-python`
and can shadow the system `cv2` that `cv_bridge` needs.

YOLO weights (`best_wrist.pt` etc.) are **not in this repo**. Without them, `camera_perception`'s node
still starts, logs a load error, and keeps publishing AprilTags/point cloud (see README "What is
computed" — YOLO failure is non-fatal). Copy real weights into `yolo_models_dir` if you want detections;
otherwise skip and only validate tags/cloud/hub wiring.

Stereo depth weights: the RAFT ones (`raft-realtime`, the Nano's model) are **downloaded** into
`depth_models_dir` on the first start. The ZED X runs **fast-foundation** (Fast-FoundationStereo), whose
checkout is **not in this repo** and is not downloadable: pass `depth_repo:=<checkout>` (or put it in
`<depth_models_dir>/Fast-FoundationStereo`), with its `pretrained_models/model_best_bp2_serialize.pth`.
Without it the ZED X depth node logs the error and falls back to raft-realtime, which still works but
flickers about three times as much (README, "Depth models"). To check what a running node uses:

```bash
ros2 param get /zedx/zedx_depth model             # fast-foundation, or raft-realtime after a fallback
ros2 param get /zedx/zedx_depth temporal_frames   # 5 on the ZED X, 1 on the Nano
```

## 4. Unit tests first — this is what actually proves the Humble port works

These use a synthetic Xavier server and a stub robot, so they need **no real camera hardware** and are
the right way to validate the port before touching anything live:

```bash
export ROS_DOMAIN_ID=73 ROS_AUTOMATIC_DISCOVERY_RANGE=LOCALHOST   # keep test traffic off the robot network
colcon test --packages-select zedx_nano_camera zedx_nano_depth camera_ui camera_perception --event-handlers=console_direct+
colcon test-result --verbose
```

For `camera_perception` specifically, if you don't have real YOLO weights available:

```bash
YOLO_OFFLINE=1 colcon test --packages-select camera_perception --event-handlers=console_direct+
```

Expected skips, not failures:
- RAFT-Stereo (neural depth) test needs a real CUDA GPU — only runs if the container has `runtime: nvidia`
  and a GPU is actually present. SGBM (CPU) backend tests always run.
- `camera_ui` page test drives headless Chrome — skipped without `google-chrome`/`chromium` +
  `websocket-client` installed in the container.
- rclpy-dependent tests are skipped if `rclpy` isn't importable (shouldn't happen here — it's ROS base).

## 5. Launch smoke test via `perception_bringup`

This is the thing we just built — verify it starts the full stack **except** the `camera_ui` web page:

```bash
ros2 launch perception_bringup perception.launch.xml
```

In another shell on the same container:

```bash
ros2 node list
# expect: /camera_hub, /zedx/zedx_camera, /zedx/zedx_depth, /zedx_nano/zedx_nano_camera, /zedx_nano/zedx_nano_depth,
#         /zedx/zedx_perception, /zedx_nano/zedx_nano_perception
# must NOT see a camera_ui / ui_node — if it's there, with_cameras wiring pulled in the wrong launch file

curl -sf http://127.0.0.1:8001/ && echo "UI PAGE IS RUNNING (should have failed to connect)"

ros2 topic echo --once /camera_hub/status
```

### Important limitation: no real cameras reach this container

SITL runs on `autolab_network` (172.31.0.0/24), not the robot's LAN, so the Xavier camera hub at
`192.168.1.101:8090` (the default `host` arg) is unreachable here. With no hub reachable:
- `camera_hub_node` logs poll errors and publishes `/camera_hub/status` with `reachable: false` — that's
  expected in SITL, not a bug.
- The camera/depth nodes will sit idle waiting for the hub; no `/zedx/...` or `/zedx_nano/...` image/depth
  topics will actually carry data.
- `camera_perception` nodes still come up and stay alive (they tolerate absent depth), but publish nothing
  useful without a live feed.

So the launch smoke test above only proves **node wiring and startup are correct**, not that images flow
end to end. For that you need the real Xavier reachable — either:
- point `host`/`port` at a reachable test server if you have one, or
- run on the `hitl`/`deploy` profile on the actual Jetson, on the robot's LAN.

## 6. What "done" looks like

- `colcon build` succeeds for all 5 packages with no `--symlink-install`.
- `colcon test` passes (or only has the expected hardware-gated skips from step 4).
- `ros2 launch perception_bringup perception.launch.xml` brings up every node in the "expect" list above,
  port 8001 refuses connections, and `/camera_hub/status` publishes (even if `reachable: false` in SITL).
- If you have hub/network access or real weights, confirm `/inspect/*`, `/servo/*` and `/zed_pointcloud`
  actually carry data — that step needs the real Xavier and is out of scope for a SITL-only check.

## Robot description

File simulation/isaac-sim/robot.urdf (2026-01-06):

<?xml version="1.0" ?>
<robot name="demo_bot">
  <link name="Chasis_1">
    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
    <inertial>
      <mass value="0"/>
      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
      <origin xyz="-0.024356086 -0.021063845 -0.009553892" rpy="0 0 0"/>
    </inertial>
  </link>
  <link name="WS2_1">
    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
    <inertial>
      <mass value="0"/>
      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
      <origin xyz="0.066675 -0.066675 -0.10874375" rpy="0 0 0"/>
    </inertial>
  </link>
  <link name="WS1_1">
    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
    <inertial>
      <mass value="0"/>
      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
      <origin xyz="0.066675 0.066675 -0.10874375" rpy="0 0 0"/>
    </inertial>
  </link>
  <link name="WS4_1">
    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
    <inertial>
      <mass value="0"/>
      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
      <origin xyz="0.066675 -0.066675 -0.10874375" rpy="0 0 0"/>
    </inertial>
  </link>
  <link name="WS3_1">
    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
    <inertial>
      <mass value="0"/>
      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
      <origin xyz="0.066675 0.066675 -0.10874375" rpy="0 0 0"/>
    </inertial>
  </link>
  <link name="X_arm_6_v1_1">
    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
    <inertial>
      <mass value="0"/>
      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
      <origin xyz="0.031952841 0.062190364 -0.21895795" rpy="0 0 0"/>
    </inertial>
  </link>
  <link name="Wheel2_1">
    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
    <inertial>
      <mass value="0"/>
      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
      <origin xyz="0.066675 0.0508 -0.06874688" rpy="0 0 0"/>
    </inertial>
  </link>
  <link name="Wheel1_1">
    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
    <inertial>
      <mass value="0"/>
      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
      <origin xyz="0.066675 -0.0508 -0.06874688" rpy="0 0 0"/>
    </inertial>
  </link>
  <link name="Wheel4_1">
    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
    <inertial>
      <mass value="0"/>
      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
      <origin xyz="0.066675 0.0508 -0.06874688" rpy="0 0 0"/>
    </inertial>
  </link>
  <link name="Wheel3_1">
    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
    <inertial>
      <mass value="0"/>
      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
      <origin xyz="0.066675 -0.0508 -0.06874688" rpy="0 0 0"/>
    </inertial>
  </link>
  <link name="grip_v1_1">
    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
    <inertial>
      <mass value="0"/>
      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
      <origin xyz="-0.15695785 -0.0093419125 0.38328126" rpy="0 0 0"/>
    </inertial>
  </link>
  <link name="Component4_2">
    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
    <inertial>
      <mass value="0"/>
      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
      <origin xyz="0 0 0.0315" rpy="0 0 0"/>
    </inertial>
  </link>
  <link name="Component4Mirror_2">
    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
    <inertial>
      <mass value="0"/>
      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
      <origin xyz="0 0 0.0315" rpy="0 0 0"/>
    </inertial>
  </link>
  <joint name="Revolute_5" type="revolute">
    <origin xyz="0.183325 -0.27388 0.10874375" rpy="9.3813846e-16 0 -2.9582284e-31"/>
    <parent link="Chasis_1"/>
    <child link="WS2_1"/>
    <axis xyz="0 0 -1"/>
    <limit effort="1" velocity="1" lower="-6.2831853" upper="6.2831853"/>
  </joint>
  <joint name="Revolute_6" type="revolute">
    <origin xyz="0.183325 0.23352665 0.1081421" rpy="-4.4408921e-16 0 5.5511151e-17"/>
    <parent link="Chasis_1"/>
    <child link="WS1_1"/>
    <axis xyz="0 0 -1"/>
    <limit effort="1" velocity="1" lower="-6.2831853" upper="6.2831853"/>
  </joint>
  <joint name="Revolute_7" type="revolute">
    <origin xyz="-0.324084 0.233325 0.10874375" rpy="2.220446e-16 0 -3.1415927"/>
    <parent link="Chasis_1"/>
    <child link="WS4_1"/>
    <axis xyz="0 0 -1"/>
    <limit effort="1" velocity="1" lower="-6.2831853" upper="6.2831853"/>
  </joint>
  <joint name="Revolute_8" type="revolute">
    <origin xyz="-0.324084 -0.274087 0.10874375" rpy="2.2870594e-14 0 3.1415927"/>
    <parent link="Chasis_1"/>
    <child link="WS3_1"/>
    <axis xyz="0 0 -1"/>
    <limit effort="1" velocity="1" lower="-6.2831853" upper="6.2831853"/>
  </joint>
  <joint name="Fastened_1" type="fixed">
    <origin xyz="0.13507607 -0.019924 0.74" rpy="3.1415927 0 1.5707963"/>
    <parent link="Chasis_1"/>
    <child link="X_arm_6_v1_1"/>
  </joint>
  <joint name="Revolute_1" type="revolute">
    <origin xyz="0 0.0024615 -0.05794375" rpy="-1.5707963 0 0"/>
    <parent link="WS2_1"/>
    <child link="Wheel2_1"/>
    <axis xyz="0 0 -1"/>
    <limit effort="1" velocity="1" lower="-6.2831853" upper="6.2831853"/>
  </joint>
  <joint name="Revolute_2" type="revolute">
    <origin xyz="0 -0.0024615 -0.05794375" rpy="1.5707963 0 0"/>
    <parent link="WS1_1"/>
    <child link="Wheel1_1"/>
    <axis xyz="0 0 -1"/>
    <limit effort="1" velocity="1" lower="-6.2831853" upper="6.2831853"/>
  </joint>
  <joint name="Revolute_3" type="revolute">
    <origin xyz="0 0.0024615 -0.05794375" rpy="-1.5707963 0 0"/>
    <parent link="WS4_1"/>
    <child link="Wheel4_1"/>
    <axis xyz="0 0 -1"/>
    <limit effort="1" velocity="1" lower="-6.2831853" upper="6.2831853"/>
  </joint>
  <joint name="Revolute_4" type="revolute">
    <origin xyz="0 -0.0024615 -0.05794375" rpy="1.5707963 0 0"/>
    <parent link="WS3_1"/>
    <child link="Wheel3_1"/>
    <axis xyz="0 0 -1"/>
    <limit effort="1" velocity="1" lower="-6.2831853" upper="6.2831853"/>
  </joint>
  <joint name="Fastened_3" type="fixed">
    <origin xyz="-0.0052042433 0.23442082 -0.15121404" rpy="-3.1371528 -0.0035313993 -3.0796106"/>
    <parent link="X_arm_6_v1_1"/>
    <child link="grip_v1_1"/>
  </joint>
  <joint name="Fastened_2" type="fixed">
    <origin xyz="3.6448224e-34 1.1423074e-35 -0.112" rpy="0 0 0"/>
    <parent link="X_arm_6_v1_1"/>
    <child link="X_arm_6_v1_1"/>
  </joint>
  <joint name="Slider_1" type="prismatic">
    <origin xyz="0.016342665 -0.00016104958 -0.060641234" rpy="-1.5707963 -1.4714163e-10 1.6231719"/>
    <parent link="grip_v1_1"/>
    <child link="Component4_2"/>
    <axis xyz="0 0 -1"/>
    <limit effort="1" velocity="1" lower="-0.1" upper="0.1"/>
  </joint>
  <joint name="Slider_2" type="prismatic">
    <origin xyz="-0.017402084 -0.0019300664 -0.060641234" rpy="1.5707963 -1.4714052e-10 1.6231719"/>
    <parent link="grip_v1_1"/>
    <child link="Component4Mirror_2"/>
    <axis xyz="0 0 -1"/>
    <limit effort="1" velocity="1" lower="-0.1" upper="0.1"/>
  </joint>
</robot>

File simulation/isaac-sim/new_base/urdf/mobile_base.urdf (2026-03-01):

<?xml version="1.0"?>
<robot name="mobile_base">
  <link name="world"/>

  <joint name="world_to_base" type="fixed">
    <parent link="world"/>
    <child link="base_link"/>
    <origin xyz="0 0 0" rpy="0 3.14159265358979 0"/>
  </joint>

  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
  <link name="base_link">
    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

    <inertial>
      <origin xyz="0 0 0" rpy="0 0 0"/>
      <mass value="25.0"/> 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
    </inertial>
  </link>

  <link name="arm_shoulder_4_2">
    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

    <inertial>
      <origin xyz="0 0 0" rpy="0 0 0"/>
      <mass value="5.0"/>
      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
    </inertial>
  </link>

    
  <link name="arm_shoulder_4_1">
    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
    <inertial>
      <origin xyz="0 0 0" rpy="0 0 0"/>
      <mass value="0.5"/>
      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
    </inertial>
  </link>


  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
  <link name="Az_Front_right_1">
    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
    <inertial>
      <origin xyz="0 0 0" rpy="0 0 0"/>
      <mass value="0.6"/>
      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
    </inertial>
  </link>

  <link name="Az_Front_Left_1">
    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
    <inertial>
      <origin xyz="0 0 0" rpy="0 0 0"/>
      <mass value="0.6"/>
      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
    </inertial>
  </link>

  <link name="Az_Back_Right_1">
    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
    <inertial>
      <origin xyz="0 0 0" rpy="0 0 0"/>
      <mass value="0.6"/>
      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
    </inertial>
  </link>

  <link name="Az_Back_left_1">
    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
    <inertial>
      <origin xyz="0 0 0" rpy="0 0 0"/>
      <mass value="0.6"/>
      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
    </inertial>
  </link>

  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
  <link name="Wheel_Front_Right_1">
    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
    <inertial>
      <origin xyz="0 0 0" rpy="0 0 0"/>
      <mass value="0.4"/>
      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
    </inertial>
  </link>

  <link name="Wheel_Front_Left_1">
    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
    <inertial>
      <origin xyz="0 0 0" rpy="0 0 0"/>
      <mass value="0.4"/>
      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
    </inertial>
  </link>

  <link name="Wheel_Back_Right_1">
    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
    <inertial>
      <origin xyz="0 0 0" rpy="0 0 0"/>
      <mass value="0.4"/>
      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
    </inertial>
  </link>

  <link name="Wheel_Back_Left_1">
    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
    <inertial>
      <origin xyz="0 0 0" rpy="0 0 0"/>
      <mass value="0.4"/>
      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
    </inertial>
  </link>

  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
  <link name="arm_shoulder241_1">
    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
    <inertial>
      <origin xyz="0 0 0" rpy="0 0 0"/>
      <mass value="1.0"/>
      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
    </inertial>
  </link>

  <link name="arm_elbow_4_1">
    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
    <inertial>
      <origin xyz="0 0 0" rpy="0 0 0"/>
      <mass value="0.8"/>
      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
    </inertial>
  </link>

  <link name="elbow2_p4_1">
    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
    <inertial>
      <origin xyz="0 0 0" rpy="0 0 0"/>
      <mass value="0.8"/>
      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
    </inertial>
  </link>

  <link name="wrist_1_p4_1">
    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
    <inertial>
      <origin xyz="0 0 0" rpy="0 0 0"/>
      <mass value="0.5"/>
      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
    </inertial>
  </link>

  <link name="wrist_2_p4_1">
    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
    <inertial>
      <origin xyz="0 0 0" rpy="0 0 0"/>
      <mass value="0.5"/>
      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
    </inertial>
  </link>

  <link name="end_effector_p4_1">
    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
    <inertial>
      <origin xyz="0 0 0" rpy="0 0 0"/>
      <mass value="0.4"/>
      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
    </inertial>
  </link>

  <link name="gripper_v43_1">
    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
    <inertial>
      <origin xyz="0 0 0" rpy="0 0 0"/>
      <mass value="0.5"/>
      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
    </inertial>
  </link>

  <link name="Finger_left_2">
    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
    <inertial>
      <origin xyz="0 0 0" rpy="0 0 0"/>
      <mass value="0.05"/>
      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
    </inertial>
  </link>

  <link name="Finger_right_2">
    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
    <inertial>
      <origin xyz="0 0 0" rpy="0 0 0"/>
      <mass value="0.05"/>
      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
    </inertial>
  </link>

  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
  <joint name="Revolute_2" type="continuous">
    <origin xyz="0.50615805 0.105825 0.63185791" rpy="3.1415927 0 1.5707963"/>
    <parent link="base_link"/>
    <child link="Az_Front_right_1"/>
    <axis xyz="0 0 1"/>
    <dynamics damping="0.05"/>
  </joint>

  <joint name="Revolute_1" type="continuous">
    <origin xyz="-0.0012486 0.105825 0.63125626" rpy="-3.1415927 0 1.5707963"/>
    <parent link="base_link"/>
    <child link="Az_Front_Left_1"/>
    <axis xyz="0 0 1"/>
    <dynamics damping="0.05"/>
  </joint>

  <joint name="Revolute_5" type="continuous">
    <origin xyz="0.5059564 -0.401584 0.63125626" rpy="-3.1415927 0 -1.5707963"/>
    <parent link="base_link"/>
    <child link="Az_Back_Right_1"/>
    <axis xyz="0 0 1"/>
    <dynamics damping="0.05"/>
  </joint>

  <joint name="Revolute_6" type="continuous">
    <origin xyz="-0.0014556 -0.401584 0.63125626" rpy="-3.1415927 0 -1.5707963"/>
    <parent link="base_link"/>
    <child link="Az_Back_left_1"/>
    <axis xyz="0 0 1"/>
    <dynamics damping="0.05"/>
  </joint>

  <joint name="Fastened_3" type="fixed">
    <parent link="base_link"/>
    <child link="arm_shoulder_4_2"/>
    <origin xyz="0.12 1.16 -0.211" rpy="0 1.5707963 0"/> 
    <dynamics dont_collapse="true"/>
  </joint>

  <joint name="Fastened_4" type="fixed">
    <origin xyz="-0.28094319 -1.3564931 -0.37430478" rpy="0 0 0"/>
    <parent link="arm_shoulder_4_2"/> 
    <child link="arm_shoulder_4_1"/>
    <dynamics dont_collapse="true"/>
  </joint>

  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
  <joint name="Revolute_9" type="revolute">
    <origin xyz="0 0 0.04" rpy="0 0 1.5707963"/>
    <parent link="arm_shoulder_4_1"/>
    <child link="arm_shoulder241_1"/>
    <axis xyz="0 0 -1"/>
    <limit effort="1" velocity="1" lower="-6.2831853" upper="6.2831853"/>
    <dynamics damping="0.02"/>
  </joint>

  <joint name="Revolute_10" type="revolute">
    <origin xyz="0 0.0775 -0.115" rpy="1.5707963 1.5707963 0"/>
    <parent link="arm_shoulder241_1"/>
    <child link="arm_elbow_4_1"/>
    <axis xyz="0 0 -1"/>
    <limit effort="1" velocity="1" lower="-6.2831853" upper="6.2831853"/>
    <dynamics damping="0.02"/>
  </joint>

  <joint name="Revolute_11" type="revolute">
    <origin xyz="0.28467 -0.05322 0.00817" rpy="0 0 0"/>
    <parent link="arm_elbow_4_1"/>
    <child link="elbow2_p4_1"/>
    <axis xyz="0 0 -1"/>
    <limit effort="1" velocity="1" lower="-6.2831853" upper="6.2831853"/>
    <dynamics damping="0.02"/>
  </joint>

  <joint name="Revolute_12" type="revolute">
    <origin xyz="-0.16933092 -0.08577945 0.06658" rpy="0 1.5707963 0"/>
    <parent link="elbow2_p4_1"/>
    <child link="wrist_1_p4_1"/>
    <axis xyz="0 0 -1"/>
    <limit effort="1" velocity="1" lower="-6.2831853" upper="6.2831853"/>
    <dynamics damping="0.02"/>
  </joint>
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

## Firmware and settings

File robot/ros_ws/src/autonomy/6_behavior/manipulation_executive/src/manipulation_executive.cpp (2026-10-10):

#include <manipulation_executive/manipulation_executive.hpp>

#include <boost/beast/core.hpp>
#include <boost/beast/websocket.hpp>
#include <boost/asio/connect.hpp>
#include <boost/asio/ip/tcp.hpp>

#include <thread>
#include <chrono>

using namespace std::chrono_literals;

namespace beast     = boost::beast;
namespace websocket = beast::websocket;
namespace net       = boost::asio;
using     tcp       = net::ip::tcp;

// ─────────────────────────────────────────────────────────────────────────────
// Constructor
// ─────────────────────────────────────────────────────────────────────────────

ManipulationExecutive::ManipulationExecutive()
    : Node("manipulation_executive")
{
    this->declare_parameter<std::string>("camera_edge_host",       "localhost");
    this->declare_parameter<int>        ("camera_edge_port",       8765);
    this->declare_parameter<double>     ("place_wait_s",           10.0);

    this->get_parameter("camera_edge_host",       camera_edge_host_);
    this->get_parameter("camera_edge_port",       camera_edge_port_);
    this->get_parameter("place_wait_s",           place_wait_s_);

    RCLCPP_INFO(this->get_logger(), "Camera-edge: %s:%d",
                camera_edge_host_.c_str(), camera_edge_port_);

    // BT conditions
    pick_up_condition_       = new bt::Condition("Pick Up Commanded",        this);
    place_condition_         = new bt::Condition("Place Commanded",          this);
    pick_base_condition_     = new bt::Condition("Pick Base Commanded",      this);
    pick_wellplate_condition_= new bt::Condition("Pick Wellplate Commanded", this);
    conditions_.push_back(pick_up_condition_);
    conditions_.push_back(place_condition_);
    conditions_.push_back(pick_base_condition_);
    conditions_.push_back(pick_wellplate_condition_);

    // BT actions
    pick_up_action_        = new bt::Action("Pick Up Object",    this);
    place_action_          = new bt::Action("Place Object",      this);
    pick_base_action_      = new bt::Action("Pick Base Object",  this);
    pick_wellplate_action_ = new bt::Action("Pick Wellplate",    this);
    actions_.push_back(pick_up_action_);
    actions_.push_back(place_action_);
    actions_.push_back(pick_base_action_);
    actions_.push_back(pick_wellplate_action_);

    // Phase publisher — monitor with: ros2 topic echo /behavior/manipulation_phase
    phase_pub_ = this->create_publisher<std_msgs::msg::String>("manipulation_phase", 10);

    // Planning command publisher
    planning_cmd_pub_ = this->create_publisher<std_msgs::msg::String>("/planning_command", 10);

    // Planning state subscriber — sets result flag read by run_planning() in its async thread.
    // Only SUCCESS and ERROR update the flag; IDLE/PLANNING/EXECUTING are ignored.
    planning_state_sub_ = this->create_subscription<std_msgs::msg::String>(
        "/planning_state", 10,
        [this](const std_msgs::msg::String::SharedPtr msg) {
            if      (msg->data == "SUCCESS") planning_result_.store(1);
            else if (msg->data == "ERROR")   planning_result_.store(2);
        });

    // Command subscription
    cmd_sub_ = this->create_subscription<behavior_tree_msgs::msg::ManipulationCommand>(
        "manipulation_command", 10,
        std::bind(&ManipulationExecutive::command_callback, this, std::placeholders::_1));

    // Debug-tool: manual camera-edge mode command, guarded to only run when idle.
    camera_mode_status_pub_ = this->create_publisher<std_msgs::msg::String>(
        "perception/camera_mode_status", 10);
    camera_mode_cmd_sub_ = this->create_subscription<std_msgs::msg::String>(
        "perception/camera_mode_cmd", 10,
        std::bind(&ManipulationExecutive::camera_mode_cmd_callback, this, std::placeholders::_1));

    // 20 Hz timer
    timer_ = rclcpp::create_timer(
        this, this->get_clock(), rclcpp::Duration::from_seconds(1.0 / 20.0),
        std::bind(&ManipulationExecutive::timer_callback, this));
}

// ─────────────────────────────────────────────────────────────────────────────
// Command callback — arms the BT conditions so the tree activates the action
// ─────────────────────────────────────────────────────────────────────────────

void ManipulationExecutive::command_callback(
    const behavior_tree_msgs::msg::ManipulationCommand::SharedPtr msg)
{
    if (manip_phase_ != ManipPhase::IDLE) {
        RCLCPP_WARN(this->get_logger(),
                    "Manipulation in progress — ignoring new command");
        return;
    }

    object_type_    = msg->object_type;
    target_machine_ = msg->target_machine;

    if (msg->type == "pick_up") {
        pick_up_condition_->set(true);
        place_condition_->set(false);
        pick_base_condition_->set(false);
        pick_wellplate_condition_->set(false);
        RCLCPP_INFO(this->get_logger(), "Received pick_up command (object: %s)",
                    object_type_.c_str());
    } else if (msg->type == "place") {
        place_condition_->set(true);
        pick_up_condition_->set(false);
        pick_base_condition_->set(false);
        pick_wellplate_condition_->set(false);
        RCLCPP_INFO(this->get_logger(), "Received place command (object: %s → machine: %s)",
                    object_type_.c_str(), target_machine_.c_str());
    } else if (msg->type == "pick_base") {
        pick_base_condition_->set(true);
        pick_up_condition_->set(false);
        place_condition_->set(false);
        pick_wellplate_condition_->set(false);
        RCLCPP_INFO(this->get_logger(), "Received pick_base command (object: %s)",
                    object_type_.c_str());
    } else if (msg->type == "pick_wellplate") {
        pick_wellplate_condition_->set(true);
        pick_up_condition_->set(false);
        place_condition_->set(false);
        pick_base_condition_->set(false);
        RCLCPP_INFO(this->get_logger(), "Received pick_wellplate command (machine: %s)",
                    target_machine_.c_str());
    } else {
        RCLCPP_WARN(this->get_logger(), "Unknown manipulation type '%s' — ignoring",
                    msg->type.c_str());
    }
}

// ─────────────────────────────────────────────────────────────────────────────
// Manual camera-mode command — debug tool. Only runs when idle; does not
// interact with the pick/place state machine's own use of activate_camera_mode.
// ─────────────────────────────────────────────────────────────────────────────

void ManipulationExecutive::camera_mode_cmd_callback(const std_msgs::msg::String::SharedPtr msg)
{
    if (!camera_mode_cmd_allowed(manip_phase_)) {
        RCLCPP_WARN(this->get_logger(),
                    "Ignoring manual camera-mode command '%s' — manipulation in progress",
                    msg->data.c_str());
        std_msgs::msg::String status;
        status.data = "busy";
        camera_mode_status_pub_->publish(status);
        return;
    }

    const std::string mode = msg->data;
    RCLCPP_INFO(this->get_logger(), "Manual camera-mode command: '%s'", mode.c_str());

    // Fire-and-forget: this is a standalone debug action, not part of
    // tick_manip()'s pending_/in_flight_ future-polling machinery.
    std::thread([this, mode]() {
        bool ok = activate_camera_mode(mode, /*wait_complete=*/false);
        std_msgs::msg::String status;
        status.data = ok ? "activated" : "failed";
        camera_mode_status_pub_->publish(status);
    }).detach();
}

// ─────────────────────────────────────────────────────────────────────────────
// Timer callback — 20 Hz
// ─────────────────────────────────────────────────────────────────────────────

static const char* phase_name(ManipulationExecutive::ManipPhase p)
{
    switch (p) {
        case ManipulationExecutive::ManipPhase::IDLE:               return "IDLE";
        case ManipulationExecutive::ManipPhase::ACTIVATING_INSPECT: return "ACTIVATING_INSPECT";
        case ManipulationExecutive::ManipPhase::PLANNING:           return "PLANNING";
        case ManipulationExecutive::ManipPhase::WAITING_PLACE:      return "WAITING_PLACE";
        case ManipulationExecutive::ManipPhase::ACTIVATING_SERVO:   return "ACTIVATING_SERVO";
        case ManipulationExecutive::ManipPhase::PLANNING_SAFE:      return "PLANNING_SAFE";
        default:                                                     return "UNKNOWN";
    }
}

void ManipulationExecutive::timer_callback()
{
    tick_manip(pick_up_action_,        ManipType::PICK_UP);
    tick_manip(place_action_,          ManipType::PLACE);
    tick_manip(pick_base_action_,      ManipType::PICK_BASE);
    tick_manip(pick_wellplate_action_, ManipType::PICK_WELLPLATE);

    // Publish current phase for monitoring
    std_msgs::msg::String phase_msg;
    phase_msg.data = phase_name(manip_phase_);
    phase_pub_->publish(phase_msg);

    for (auto* c : conditions_) c->publish();
    for (auto* a : actions_)    a->publish();
}

// ─────────────────────────────────────────────────────────────────────────────
// Shared manipulation state machine
// ─────────────────────────────────────────────────────────────────────────────

void ManipulationExecutive::tick_manip(bt::Action* action, ManipType type)
{
    if (!action->is_active()) {
        if (action->active_has_changed()) reset_manip();
        return;
    }

    if (manip_terminal_) return;

    // ── New activation ────────────────────────────────────────────────────────
    if (action->active_has_changed()) {
        manip_type_ = type;
        const char* type_name =
            (type == ManipType::PICK_UP)        ? "pick_up"        :
            (type == ManipType::PLACE)          ? "place"          :
            (type == ManipType::PICK_BASE)      ? "pick_base"      :
                                                  "pick_wellplate";
        RCLCPP_INFO(this->get_logger(), "Manipulation activated (%s)", type_name);

        if (type == ManipType::PICK_BASE) {
            // pick_base: skip inspect, go straight to planning home_offset
            manip_phase_ = ManipPhase::PLANNING;
            in_flight_   = true;
            pending_ = std::async(std::launch::async,
                                  &ManipulationExecutive::run_planning,
                                  this, "home_offset");
        } else if (type == ManipType::PICK_WELLPLATE) {
            // pick_wellplate: plan to april tag (via target_machine), then servo, then safe home
            manip_phase_ = ManipPhase::PLANNING;
            in_flight_   = true;
            pending_ = std::async(std::launch::async,
                                  &ManipulationExecutive::run_planning,
                                  this, "wellplate_placement");
        } else {
            manip_phase_ = ManipPhase::ACTIVATING_INSPECT;
            in_flight_   = true;
            pending_ = std::async(std::launch::async,
                                  &ManipulationExecutive::activate_camera_mode,
                                  this, "inspect", false);
        }
        action->set_running();
        return;
    }

    // ── ACTIVATING_INSPECT ────────────────────────────────────────────────────
    if (manip_phase_ == ManipPhase::ACTIVATING_INSPECT) {
        if (pending_.wait_for(std::chrono::milliseconds(0)) == std::future_status::ready) {
            in_flight_ = false;
            if (!pending_.get()) {
                RCLCPP_ERROR(this->get_logger(), "Failed to activate inspect mode — FAILURE");
                fail_manip(action);
                return;
            }
            RCLCPP_INFO(this->get_logger(), "Inspect mode active — triggering planning");
            manip_phase_ = ManipPhase::PLANNING;
            in_flight_   = true;
            // pick_up → inspection pose; place → placement pose
            std::string pose_type = (manip_type_ == ManipType::PICK_UP) ? "inspection" : "placement";
            pending_ = std::async(std::launch::async,
                                  &ManipulationExecutive::run_planning,
                                  this, pose_type);
        }
        action->set_running();
        return;
    }

    // ── PLANNING ──────────────────────────────────────────────────────────────
    if (manip_phase_ == ManipPhase::PLANNING) {
        if (pending_.wait_for(std::chrono::milliseconds(0)) == std::future_status::ready) {
            in_flight_ = false;
            if (!pending_.get()) {
                RCLCPP_ERROR(this->get_logger(), "Planning failed — FAILURE");
                fail_manip(action);
                return;
            }
            if (manip_type_ == ManipType::PLACE) {
                RCLCPP_INFO(this->get_logger(),
                            "Planning complete — waiting %.1f s before safe position",
                            place_wait_s_);
                manip_phase_ = ManipPhase::WAITING_PLACE;
                in_flight_   = true;
                const double wait_s = place_wait_s_;
                pending_ = std::async(std::launch::async, [wait_s]() -> bool {
                    std::this_thread::sleep_for(
                        std::chrono::duration<double>(wait_s));
                    return true;
                });
            } else {
                RCLCPP_INFO(this->get_logger(), "Planning complete — activating servo mode");
                manip_phase_ = ManipPhase::ACTIVATING_SERVO;
                in_flight_   = true;
                pending_ = std::async(std::launch::async,
                                      &ManipulationExecutive::activate_camera_mode,
                                      this, "servo", true);
            }
        }
        action->set_running();
        return;
    }

    // ── WAITING_PLACE ─────────────────────────────────────────────────────────
    if (manip_phase_ == ManipPhase::WAITING_PLACE) {
        if (pending_.wait_for(std::chrono::milliseconds(0)) == std::future_status::ready) {
            in_flight_ = false;
            pending_.get(); // always true
            RCLCPP_INFO(this->get_logger(), "Wait complete — planning safe position");
            manip_phase_ = ManipPhase::PLANNING_SAFE;
            in_flight_   = true;
            pending_ = std::async(std::launch::async,
                                  &ManipulationExecutive::run_planning,
                                  this, "safe");
        }
        action->set_running();
        return;
    }


    // ── ACTIVATING_SERVO ──────────────────────────────────────────────────────
    if (manip_phase_ == ManipPhase::ACTIVATING_SERVO) {
        if (pending_.wait_for(std::chrono::milliseconds(0)) == std::future_status::ready) {
            in_flight_ = false;
            if (!pending_.get()) {
                RCLCPP_ERROR(this->get_logger(), "Servo mode did not complete — FAILURE");
                fail_manip(action);
                return;
            }
            if (manip_type_ == ManipType::PICK_BASE) {
                // pick_base ends here — no safe-home planning needed
                RCLCPP_INFO(this->get_logger(), "Servo complete — pick_base SUCCESS");
                pick_base_condition_->set(false);
                manip_phase_    = ManipPhase::IDLE;
                manip_terminal_ = true;
                action->set_success();
                return;
            } else {
                RCLCPP_INFO(this->get_logger(), "Servo complete — planning safe position");
                manip_phase_ = ManipPhase::PLANNING_SAFE;
                in_flight_   = true;
                pending_ = std::async(std::launch::async,
                                      &ManipulationExecutive::run_planning,
                                      this, "safe");
            }
        }
        action->set_running();
        return;
    }

    // ── PLANNING_SAFE ─────────────────────────────────────────────────────────
    if (manip_phase_ == ManipPhase::PLANNING_SAFE) {
        if (pending_.wait_for(std::chrono::milliseconds(0)) == std::future_status::ready) {
            in_flight_ = false;
            if (!pending_.get()) {
                RCLCPP_ERROR(this->get_logger(), "Safe planning failed — FAILURE");
                fail_manip(action);
                return;
            }
            RCLCPP_INFO(this->get_logger(), "Manipulation complete — SUCCESS");
            bt::Condition* cond =
                (manip_type_ == ManipType::PICK_UP)         ? pick_up_condition_       :
                (manip_type_ == ManipType::PLACE)            ? place_condition_         :
                (manip_type_ == ManipType::PICK_WELLPLATE)   ? pick_wellplate_condition_:
                                                               pick_base_condition_;
            cond->set(false);
            manip_phase_    = ManipPhase::IDLE;
            manip_terminal_ = true;
            action->set_success();
            return;
        }
        action->set_running();
        return;
    }
}

void ManipulationExecutive::reset_manip()
{
    manip_phase_    = ManipPhase::IDLE;
    manip_terminal_ = false;
    in_flight_      = false;
}

void ManipulationExecutive::fail_manip(bt::Action* action)
{
    bt::Condition* cond =
        (manip_type_ == ManipType::PICK_UP)       ? pick_up_condition_       :
        (manip_type_ == ManipType::PLACE)          ? place_condition_         :
        (manip_type_ == ManipType::PICK_BASE)      ? pick_base_condition_     :
                                                     pick_wellplate_condition_;
    cond->set(false);
    manip_phase_    = ManipPhase::IDLE;
    manip_terminal_ = true;
    action->set_failure();
}

// ─────────────────────────────────────────────────────────────────────────────
// Camera-edge WebSocket helper
// ─────────────────────────────────────────────────────────────────────────────

std::string ManipulationExecutive::ws_round_trip(const std::string& msg)
{
    try {
        net::io_context ioc;
        tcp::resolver resolver{ioc};
        websocket::stream<tcp::socket> ws{ioc};

        auto const results = resolver.resolve(camera_edge_host_,
                                              std::to_string(camera_edge_port_));
        net::connect(ws.next_layer(), results.begin(), results.end());
        ws.handshake(camera_edge_host_, "/");

        // Server sends a greeting on connect ("connected") — drain it before sending
        beast::flat_buffer greeting;
        ws.read(greeting);

        ws.write(net::buffer(msg));

        beast::flat_buffer buffer;
        ws.read(buffer);
        ws.close(websocket::close_code::normal);

        return beast::buffers_to_string(buffer.data());
    } catch (const std::exception& e) {
        RCLCPP_ERROR(this->get_logger(), "WebSocket error: %s", e.what());
        return "";
    }
}

// ─────────────────────────────────────────────────────────────────────────────
// activate_camera_mode — runs in std::async thread
//
// Sends { "cmd": "mode", "mode": <mode> }, then polls { "cmd": "status" }.
//
// Response format: { "mode": "<current_mode>", "worker_alive": <bool> }
//   worker_alive == true  AND mode == sent_mode  →  mode is running (active)
//   worker_alive == false OR  mode == "idle"     →  not running (failed/idle)
//
// wait_complete == false (inspect):
//   Return true once worker_alive==true && mode==sent_mode (confirmed active).
//   Return false immediately if worker_alive==false (failed to start).
//
// wait_complete == true (servo):
//   First confirm activation (worker_alive==true), then wait until the mode
//   returns to idle (worker_alive==false), which signals servo has finished.
// ─────────────────────────────────────────────────────────────────────────────
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
int main(int argc, char** argv)
{
    rclcpp::init(argc, argv);
    auto node = std::make_shared<ManipulationExecutive>();

    rclcpp::executors::MultiThreadedExecutor executor;
    executor.add_node(node);
    executor.spin();
    rclcpp::shutdown();
    return 0;
}

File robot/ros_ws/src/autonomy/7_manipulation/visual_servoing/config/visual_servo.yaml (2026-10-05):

# visual_servo_node. launch/visual_servo.launch.xml sets execute, preview, robot_ip, yolo.model, yolo.device and
# control_port from its arguments; everything else is read from here. Lengths in metres unless the name says mm.
/**:
  ros__parameters:
    camera_namespace: /zedx_nano      # zedx_nano_depth outputs: left/image_rect_color, depth/image_rect, depth/camera_info
    depth_scale: 1.0                  # multiplies the depth before use (see README: the RAFT depth may read short up close)
    select_service: /camera_hub/select_zedx_nano   # switch the hub to the Nano at the start of a run; '' = don't
    select_timeout: 20.0
    restore_camera: true              # afterwards, switch back to the camera the hub streamed before (the ZED X)
    hub_node: /camera_hub
    control_host: 0.0.0.0             # Camera-Edge control WebSocket; control_port (launch) -1 disables it

    yolo:
      model: ''                       # set by the launch file (best_wrist.pt: oriented boxes, class wellplate)
      device: cuda:0
      conf: 0.001                     # report weak candidates too; servo.min_conf decides (the plate scored 0.0025
                                      # on the arm from 147 mm up, 2026-09-22: weak ones need the depth size check)
      iou: 0.7
      imgsz: 0
      classes: ''
      clahe_clip: 0.0

    # Where the camera and the fingertips are: the CAD numbers (mount.py explains the frames). The flange is the
    # xArm tool frame without TCP offset, z towards the fingers; the camera is on its +x side.
    mount:
      camera_offset_mm: [90.711, -0.078, 5.732]   # camera reference point from the EE point
      tilt_deg: 20.0                                # optical axis tipped towards the fingers (bracket at 110 deg)
      lens_offset_mm: [-9.0, 0.0, 0.0]              # left lens from that point, camera frame (18 mm baseline)
      correction_rpy_deg: [0.0, 0.0, 0.0]           # extra camera rotation about its x, y, z
      tip_mm: [-1.022, -7.838, 109.104]             # fingertip centre from the EE point
      ee_below_flange_mm: 0.0                       # cancels out; only absolute heights in the status change
      # [x, y, z] measured in the camera frame, overrides tip_mm; [0.0] = use tip_mm. From the live depth with the
      # gripper open (2026-09-22, README "Before the first grasp"): finger ends 112.9 mm down the flange axis (CAD 109.1),
      # midway between the fingers (flange y -0.2); x, along the plate's long side, kept from the episode estimate
      tip_camera_mm: [8.9, 47.2, 131.2]

    servo:
      control_rate: 50.0              # Hz
      command_duration: 0.25          # s, the arm zeroes a velocity command it doesn't get renewed within this
      level_at_start: true            # roll 180, pitch 0 first (Camera-Edge move_to_start_pose)
      level_speed: 100.0              # mm/s
      hover_height: 0.08              # fingertips above the plate's top face when the servo ends
      grasp_offset: [0.0, 0.0]        # fingertip target shift: across the fingers, along the fingers
      finger_axis: 'y'                # flange axis the fingers close along (Camera-Edge FINGER_TOOL_AXIS)
      settle_count: 5                 # consecutive detections within tolerance that end the servo
      max_image_age: 0.5
      hold_timeout: 0.5               # s without a detection: the last plate estimate counts towards settling this often
      lost_timeout: 5.0               # s without a detection: the attempt fails
      align_timeout: 60.0             # s per attempt; 0 = none (a dry run then previews until stopped)
      max_travel: 0.25                # the fingertip target must stay within this of where the run started
      min_tip_z: -0.08                # no fingertip target below this base z
      plate_size: [0.12776, 0.08548]  # SBS footprint (long, short); also the no-depth fallback's scale
      size_tolerance: 0.35            # drop estimates whose long side is off by more than this fraction; 0 = off
      min_conf: 0.25                  # below this (yolo.conf lets them through), a detection counts only with depth
      weak_size_tolerance: 0.12       # and both sides within this fraction of plate_size (clutter drops YOLO's score)
      filter_alpha: 0.3
      filter_gate: 0.03

    gains:
      k_xy: 1.0                       # 1/s
      k_z: 1.0
      k_yaw: 1.0
      max_xy: 0.02                    # m/s (Camera-Edge clamped to 0.02)
      max_z: 0.02
      max_yaw: 0.3                    # rad/s
      tol_xy: 0.002
      tol_z: 0.004
      tol_yaw_deg: 1.5
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

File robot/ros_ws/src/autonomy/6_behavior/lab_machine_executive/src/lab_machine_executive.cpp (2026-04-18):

// Copyright (c) 2024 Carnegie Mellon University
// MIT License — see LICENSE for details.

#include <lab_machine_executive/lab_machine_executive.hpp>

using namespace std::chrono_literals;

// ─────────────────────────────────────────────────────────────────────────────
// Constructor
// ─────────────────────────────────────────────────────────────────────────────

LabMachineExecutive::LabMachineExecutive()
    : Node("lab_machine_executive"),
      ot2_current_step_(0),
      ot2_phase_(OT2Phase::IDLE),
      ot2_terminal_(false),
      http_in_flight_(false)
{
    // ROS2 parameters
    this->declare_parameter<std::string>("ot2_base_url",     "http://192.168.1.100:8000");
    this->declare_parameter<std::string>("ot2_host",         "192.168.1.100");
    this->declare_parameter<std::string>("shaker_base_url",  "http://192.168.1.101:8080");
    this->declare_parameter<std::string>("shaker_endpoint",  "/pwm");

    this->get_parameter("ot2_base_url",    ot2_base_url_);
    this->get_parameter("ot2_host",        ot2_host_);
    this->get_parameter("shaker_base_url", shaker_base_url_);
    this->get_parameter("shaker_endpoint", shaker_endpoint_);

    RCLCPP_INFO(this->get_logger(), "OT-2 base URL: %s (robot host: %s)",
                ot2_base_url_.c_str(), ot2_host_.c_str());
    RCLCPP_INFO(this->get_logger(), "Shaker base URL: %s%s",
                shaker_base_url_.c_str(), shaker_endpoint_.c_str());

    // BT conditions
    command_lab_machine_condition_ = new bt::Condition("Command Lab Machine", this);
    ot2_condition_                 = new bt::Condition("OT2 Liquid Handler", this);
    shaker_condition_              = new bt::Condition("Custom Shaker Module", this);
    conditions_.push_back(command_lab_machine_condition_);
    conditions_.push_back(ot2_condition_);
    conditions_.push_back(shaker_condition_);

    // BT actions
    ot2_action_    = new bt::Action("Execute OT2 Protocol", this);
    shaker_action_ = new bt::Action("Execute Shaker Protocol", this);
    actions_.push_back(ot2_action_);
    actions_.push_back(shaker_action_);

    // Subscription for incoming lab machine commands
    cmd_sub_ = this->create_subscription<behavior_tree_msgs::msg::LabMachineCommand>(
        "lab_machine_command", 10,
        std::bind(&LabMachineExecutive::command_callback, this, std::placeholders::_1));

    // Timer at 20 Hz to match behavior_executive cadence
    timer_ = rclcpp::create_timer(
        this, this->get_clock(), rclcpp::Duration::from_seconds(1.0 / 20.0),
        std::bind(&LabMachineExecutive::timer_callback, this));
}

// ─────────────────────────────────────────────────────────────────────────────
// LabMachineCommand subscription callback
// ─────────────────────────────────────────────────────────────────────────────

void LabMachineExecutive::command_callback(
    const behavior_tree_msgs::msg::LabMachineCommand::SharedPtr msg)
{
    if (msg->device == "ot2") {
        if (ot2_phase_ != OT2Phase::IDLE) {
            RCLCPP_WARN(this->get_logger(),
                        "OT-2 run in progress — ignoring new protocol");
            return;
        }
        ot2_protocol_json_ = msg->parameters_json;
        command_lab_machine_condition_->set(true);
        ot2_condition_->set(true);
        shaker_condition_->set(false);
        RCLCPP_INFO(this->get_logger(), "Received OT-2 protocol (%zu bytes)",
                    ot2_protocol_json_.size());
    } else if (msg->device == "shaker") {
        if (ot2_phase_ != OT2Phase::IDLE) {

            RCLCPP_WARN(this->get_logger(),
                        "OT-2 run in progress — ignoring shaker command");
            return;
        }
        if (shaker_condition_->get()) {
            RCLCPP_WARN(this->get_logger(),
                        "Shaker run in progress — ignoring new command");
            return;
        }
        shaker_protocol_json_ = msg->parameters_json;
        command_lab_machine_condition_->set(true);
        shaker_condition_->set(true);
        ot2_condition_->set(false);
        RCLCPP_INFO(this->get_logger(), "Received shaker protocol (%zu bytes)",
                    shaker_protocol_json_.size());
    } else {
        RCLCPP_WARN(this->get_logger(), "Unknown device '%s' — ignoring", msg->device.c_str());
    }
}

// ─────────────────────────────────────────────────────────────────────────────
// Static helpers
// ─────────────────────────────────────────────────────────────────────────────

// Discard HTTP response body — required by libcurl
static size_t discard_response(char*, size_t size, size_t nmemb, void*) {
    return size * nmemb;
}

bool LabMachineExecutive::http_post(const std::string& url,
                                    const std::string& body,
                                    const std::string& content_type)
{
    CURL* curl = curl_easy_init();
    if (!curl) return false;

    struct curl_slist* headers = nullptr;
    std::string ct_header = "Content-Type: " + content_type;
    headers = curl_slist_append(headers, ct_header.c_str());

    curl_easy_setopt(curl, CURLOPT_URL,           url.c_str());
    curl_easy_setopt(curl, CURLOPT_POST,           1L);
    curl_easy_setopt(curl, CURLOPT_POSTFIELDS,     body.c_str());
    curl_easy_setopt(curl, CURLOPT_POSTFIELDSIZE,  static_cast<long>(body.size()));
    curl_easy_setopt(curl, CURLOPT_HTTPHEADER,     headers);
    curl_easy_setopt(curl, CURLOPT_TIMEOUT,        30L);
    curl_easy_setopt(curl, CURLOPT_WRITEFUNCTION,  discard_response);

    CURLcode res  = curl_easy_perform(curl);
    long http_code = 0;
    curl_easy_getinfo(curl, CURLINFO_RESPONSE_CODE, &http_code);

    curl_slist_free_all(headers);
    curl_easy_cleanup(curl);

    return (res == CURLE_OK) && (http_code >= 200) && (http_code < 300);
}

bool LabMachineExecutive::home_ot2() {
    return http_post(ot2_base_url_ + "/robot/home", "{}", "application/json");
}

bool LabMachineExecutive::disconnect_ot2() {
    return http_post(ot2_base_url_ + "/robot/disconnect", "{}", "application/json");
}

// Converts OT-2 step action name to REST endpoint path.
// e.g. "pick_up_tips" → "/commands/pick-up-tips"
std::string LabMachineExecutive::action_to_endpoint(const std::string& action) {
    std::string slug = action;
    std::replace(slug.begin(), slug.end(), '_', '-');
    return "/commands/" + slug;
}
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

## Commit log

2026-01-06 Mapping and localization
    [Chasis_1.stl, Component4Mirror_2.stl, Component4_2.stl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]
2026-03-01 Base-version of motion planning
    [Az_Back_Right_1.stl, Az_Back_left_1.stl, Az_Front_Left_1.stl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]
2026-03-01 Basic planning checkpoint
    [robot.urdf]
2026-03-01 Basic planning framework
2026-03-01 Ignore large files for LFS
    [Mobile_Base.step]
2026-03-01 Ignore large files for LFS / remove from tracking
    [Mobile_Base.step]
2026-03-01 Adding dummy point cloud
    [demo_bot.ros2_control.xacro]
2026-03-18 Basic moveit+IsaacSim setup
    [96 Well Plate, F-bottom, Standard.step, OT-2 Reference Model Basic.STEP, OT-2 Reference Model Detailed.STEP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]
2026-03-29 Merge pull request #7 from MRSD-APEXLabs/jmuerto/lmi-behavior-tree
    feat: Add LMI integration to behavior tree
    [lab_machines.yaml]
2026-04-05 Jmuerto/UI camera streaming (#8)
    * feat: Add camera panels
    * feat: add guard for OT2 tick
    * feat: add guard for OT2 tick
    * fix: rollback changes for LMI
    * fix: update UI to connect to updated camera logic
2026-04-07 Jmuerto/edge integration (#9)
    * feat: integrate camera control code with behavior tree
    * feat: update to have appropriate status checker
    * feat: fix status checker
    * feat: fix status checker
    * feat: let us time out rather than failing out immediately.
    * chore: let's see what we're actually getting back from the camera.
    * chore: drain the initial greeting rather than reading that as the response from the status request.
    [manipulation_executive.cpp]
2026-04-18 Planning Integration (#10)
    * Planning Integration
    * Cleanup
    * ReadMe
    * chore: integrate planning with manipulation executive
    * more changes
    * fix: double params
    * Add a log for when we receive an execution command
    * fix: robot_name/domain_id setting
    * fix: shaker fixes
    * fix: pick up base
    * fix: pick up base
    * fix: pick up base
    * fix: update tree
    * fix: add waiting place state
    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
    [Az_Back_Right_1.stl, Az_Back_left_1.stl, Az_Front_Left_1.stl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]
2026-04-18 Svd local changes (#11)
    * config updates
    * commit local planning changes from SVD
    * more local changes
    ---------
    [lab_machines.yaml, robot.urdf]
2026-08-29 New Sim
    [robot_isaac.urdf]
2026-09-06 Svd encore (#12)
    * feat: force add perception directory
    * feat(perception): add live_detect.py as regular file
    * feat(perception): add live_detect.py script
    * Merge pull request #7 from MRSD-APEXLabs/jmuerto/lmi-behavior-tree
    * UI (#6)
    * UI
    * feat: Move UI under gcs directory and add compose architecture for DEV and PROD mode.
    * Jmuerto/UI camera streaming (#8)
    * Jmuerto/edge integration (#9)
    * feat: integrate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
    [robot.old.urdf]
2026-09-13 fix: switch to free version
2026-09-16 fix: fix motor init
2026-09-16 fix: container should start canbus interface so that we don't have to manually ssh on and start it ourselves. Add common pitfalls to README as well. Update config params to use can0 rather than human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
2026-09-16 fix: update docker compose so that sim and real options are known
    [robot-base-docker-compose.yaml]
2026-09-17 fix: motor direction
2026-09-19 Add ACT imitation-learning data collection, web viewer and Xavier record mode
    Keyboard-teleop demonstration collector for the xArm6 wrist camera (input for ACT training), under
    robot/ros_ws/src/autonomy/7_imitation_learning/ (not a ROS package: it carries a COLCON_IGNORE).
    - collect.sh: prompt -> keyboard teleop while recording -> keep/delete. 100 Hz joint/TCP/torque state, 100 Hz command
    log, ~29 Hz left/right/depth from the Xavier, per-episode clock-offset probe, one HDF5 per kept episode plus
    dataset.yaml. index.csv is rebuilt from the episode files: deleting an episode is just deleting its .hdf5.
    - A camera frame is dropped when its joint angles are exactly the same as the previous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
2026-09-19 Save planning work in progress: RRT-star / visualization planner changes, planning launch and MoveIt config
    Snapshot of the uncommitted planning work in this checkout, committed as a backup. Not reviewed or built as part of this
    commit.
    - global_planner: constrained-RRT changes (crrt_plan / crrt_types / crrt_validity / constrained_rrt), new crrt_rrtstar.hpp
    and crrt_viz.hpp, move_to_pose_node.cpp
    - planning_bringup / xarm_moveit_config / base_moveit_config_2: planning.launch.xml, xarm6_moveit_realmove.launch.py,
    moveit.rviz, sensors_3d.yaml
    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
2026-09-21 Planning improvements, top camera calibration code
2026-10-05 Integrate everything2 changes on current main
    [lab_machines.yaml, visual_servo.yaml]
2026-10-06 Add gripper side clearance box; update planning run docs
    - robot.urdf: extra 4 cm collision slab on the -x side of gripper_v43_1
    (from local_changes 3d98a7e), so plans keep sideways clearance.
    - Planning ReadMe and docs/launch-planning.md: run with the camera hub on
    the Xavier and camera_perception on the Thor instead of pc3.py; note
    that the obstacle cloud is frozen at the first plan command.
    - calibrate-top-camera.md, launch-visual-servo.md: renumbered step links.
    [robot.urdf]
2026-10-08 local changes on Thor (#18)
    [robot.urdf]
2026-10-10 Jmuerto/UI qol improvements (#19)
    * feat: add debugging console for easier testing
    * chore: add testing description to UI README
    * feat: Add options for navigation testing
    * feat: no rviz when launching gcs
    * fix: fix localhost only thing
    * fix: Fast DDS fixes for connecting gcs/robot
    * fix: add dds_lan_profile
    * fix: make sure nav stack can be controlled from nav controller
    * fix: domain bridge to map nav topics from its isolated domain to the behavior executor
    * fix: make sure we're getting status updates through
    [manipulation_executive.cpp]
2026-10-11 Jmuerto/UI new perception (#21)
    * first pass at camera integration with UI
    * Feat: initial implementation of servo integration
    Claude-Session: https://claude.ai/code/session_01YAvGrUbUBRqJj25n1XtQFS
    * update apriltag ids and docker image version
    * fix: Remove old mapping/localization launch
    * fix: Remove old mapping/localization launch
    * fix: pip/apt updates for container
    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
2026-10-18 Jmuerto/maniuplation launch (#22)
    * feat: add a manipulation launcher and integrate it into robot bringup. needs testing on actual hardware
    * fix: only top level executives should get robot_1 when launched manually or robot_bringup. everything else doesn't get that.
    * fix: manipulation launch making it down to manipulation executive
    * fix: group things
    * Visual servo FSR integration, minor perception changes
    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
2026-10-26 fix: remove servo timeout, not needed anymore since its running locally via ROS now
2026-10-26 Add UFACTORY F/T sensor to arm URDF and raise planning goals (#23)
    The 6-axis F/T sensor sits between end_effector_p4_1 and the gripper,
    so everything below the flange is 55 mm lower.
    - robot.urdf / robot_isaac.urdf: new force_sensor_link (75 mm dia x
    55 mm cylinder); Fastened_1 moved from z -0.028 to -0.083.
    - demo_bot.srdf: disable collisions between force_sensor_link and its
    neighbours / links it can never reach.
    - move_to_pose_node: plan_home z 0.247 -> 0.302 (+5.5 cm); pre-grasp
    z offset +3 cm for plan_april_* and plan_wellplate so the gripper
    does not hit the octomap at the goal.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
2026-10-26 Jmuerto/maniuplation launch (#24)
    * local changes for manipulation launching
    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
2026-10-26 Jmuerto/vs 6axis integration (#25)
    * feat: Add F/T sensor integration to visual servo
    * feat: fix code 9 failure
    * feat: start using ft
    * feat: adjust nudging routine
2026-11-06 Jmuerto/led integration (#26)
    * feat: integrate placement into routine executor
    * feat: integrate placement into routine executor
    * fix: bug w/ logger changing level
    * ACT integration
    * feat: pass target to act inference
    * Base placement
    * Pre-experiment
    * fix: use plan_wellplate not plan_apriltag for picking
    * xarm_controller_bug_fix
    * Untrack table_frames jpgs and ignore them
    * feat: command LEDs based on current robot status (what actions are executing etc)
    * chore: add README w/ testing, state->LED table, other caveats
    * feat: test script for figuring out the f/t issues.
    * feat: open/close gripper as part of f/t check script
    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
2026-11-07 Jmuerto/vs depth probe (#27)
    * feat: add a depth probe mode for vs
    * fix: adjust timing of open/close gripper commands
    * feat: change param so that its more clear how to tune the probe
2026-11-08 Jmuerto/vs probe tilt (#28)
    * feat: initial attempt at tilting the gripper to be parallel w/ the well plate
    * feat: integrate the anomaly detection pipeline
    * feat: UI integration of anomaly pipeline. DEV and PROD
    * fix: deal w/ ui build issues
    * fix: vs tilt tuning
    * Update config defaults
    * fix: vs tilt tuning
    * fix: vs tilt tuning
    * fix: vs tilt tuning
    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
2026-11-08 Jmuerto/vs probe tilt (#29)
    * navigation_final_final_2
    * final tweaks
    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
